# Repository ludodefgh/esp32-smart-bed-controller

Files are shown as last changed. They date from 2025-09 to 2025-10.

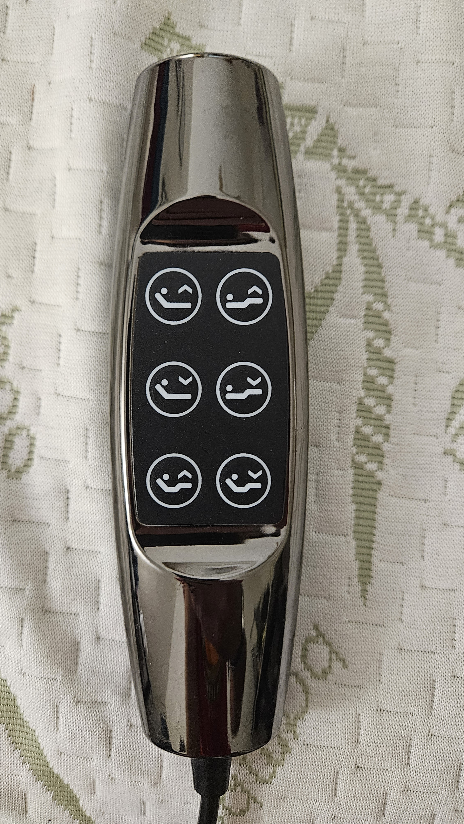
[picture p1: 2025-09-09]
remote.jpg

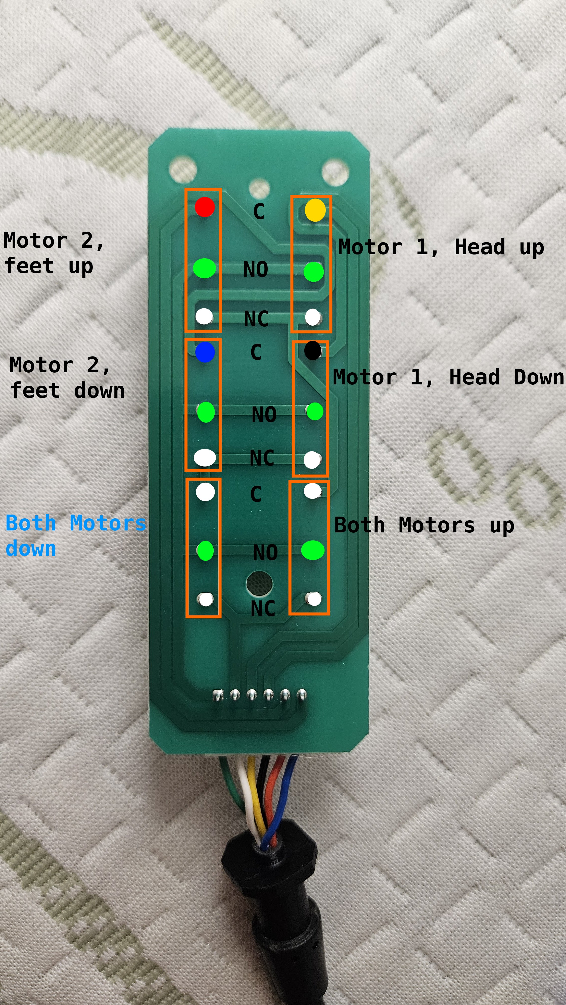
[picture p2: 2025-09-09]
remote-back.jpg

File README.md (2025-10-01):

# Smart Bed Controller with ESP32 and ESPHome

Transform your adjustable bed into a smart home device using an ESP32 microcontroller and ESPHome. This project allows you to control your bed remotely through Home Assistant while preserving the original remote functionality.

## Table of Contents

- [Overview](#overview)
- [Hardware Requirements](#hardware-requirements)
- [Wiring Guide](#wiring-guide)
- [ESPHome Configuration](#esphome-configuration)
- [Home Assistant Integration](#home-assistant-integration)
- [3D Printed Case](#3d-printed-case)
- [Installation Steps](#installation-steps)
- [Troubleshooting](#troubleshooting)
- [Safety Considerations](#safety-considerations)

## Overview

This project enables smart control of adjustable beds by intercepting and replicating the signals from the original remote control. The ESP32 board acts as an intermediary, allowing both the original remote and Home Assistant to control the bed functions.

### Features

- Control bed head and foot positions remotely via Home Assistant
- Preserve original remote functionality
- WiFi connectivity for smart home integration
- Status LED indicator
- Safe relay-based switching

## Hardware Requirements

### Essential Components

| Component | Description | Example Link |
|---|---|---|
| ESP32 Development Board | 4-relay ESP32 board with 7-30V power input | [Amazon Canada](https://www.amazon.ca/dp/B0DF2KVQ3X) |
| USB to TTL Converter | For programming the ESP32 board | [Amazon Canada](https://www.amazon.ca/dp/B07D6LLX19) |
| DIN5 Extension Cable | To interface with bed's control system | [Amazon Canada](https://www.amazon.ca/dp/B0FK5RSHBZ) |

### Tools Needed

- Wire strippers
- Soldering iron and solder
- Multimeter (recommended)
- Screwdriver set

## Wiring Guide

### Understanding the Original Remote

The bed remote uses a DIN5 connector with the following pin configuration:

| DIN5 Pin | Wire Color | Function |
|---|---|---|
| 1 | Red | Motor 2, Terminal 1 (Feet Up) |
| 2 | Yellow | Motor 1, Terminal 1 (Head Up) |
| 3 | Green | Positive (+) Power |
| 4 | Blue/Orange* | Motor 2, Terminal 2 (Feet Down) |
| 5 | Black | Motor 1, Terminal 2 (Head Down) |
| 6 | White | Negative (-) Power |

*Note: Extension cable may use orange instead of blue

### Power Connections

- **Green (+)**: Connect to ESP32 7-30V input and daisy-chain to all relay NO (Normally Open) contacts
- **White (-)**: Connect to ESP32 GND input and daisy-chain to all relay NC (Normally Closed) contacts

### Motor Control Wiring

Split the extension cable, connect the male end to the bed and wire the cables to the board as following :

| ESP32 Relay | Wire Color | Function | DIN5 Pin |
|---|---|---|---|
| Switch 1 COM | Black | Head Down | Pin 5 |
| Switch 2 COM | Orange/Blue | Feet Down | Pin 4 |
| Switch 3 COM | Yellow | Head Up | Pin 2 |
| Switch 4 COM | Red | Feet Up | Pin 1 |

### Remote Preservation Wiring

Connect the remote in the female end of the extension cable and wire the cables to ESP32 GPIO pins to maintain remote functionality:

| ESP32 GPIO | Wire Color | Function |
|---|---|---|
| GPIO 2 | Black | Head Down Detection |
| GPIO 4 | Red | Feet Up Detection |
| GPIO 17 | Yellow | Head Up Detection |
| GPIO 18 | Orange/Blue | Feet Down Detection |
| GND | Green | Ground Reference |

## ESPHome Configuration

The ESP32 runs ESPHome firmware with the provided `SmartBed.yaml` configuration. Key features:

### Relay Configuration

```yaml
output:
  - platform: gpio
    pin: GPIO32
    id: relay_pin_1  # Head Down
  - platform: gpio
    pin: GPIO33
    id: relay_pin_2  # Feet Down
  - platform: gpio
    pin: GPIO25
    id: relay_pin_3  # Head Up
  - platform: gpio
    pin: GPIO26
    id: relay_pin_4  # Feet Up
```

### Switch Definitions

```yaml
switch:
  - platform: output
    id: relay_1
    name: "Head down"
    output: relay_pin_1
  - platform: output
    id: relay_2
    name: "Feet down"
    output: relay_pin_2
  - platform: output
    id: relay_3
    name: "Head up"
    output: relay_pin_3
  - platform: output
    id: relay_4
    name: "Feet up"
    output: relay_pin_4
```

### Remote Button Detection

The configuration includes binary sensors for each remote button that trigger the corresponding relays, ensuring the original remote continues to work alongside the smart controls.

## Home Assistant Integration

Once the ESP32 is running ESPHome, it will automatically appear in Home Assistant as four switch entities:

- `switch.esphome_web_861ea0_head_down`
- `switch.esphome_web_861ea0_head_up`
- `switch.esphome_web_861ea0_feet_down`
- `switch.esphome_web_861ea0_feet_up`

These can be used in automations, scripts, and dashboards.

## 3D Printed Case

A custom 3D printable case is provided to protect the ESP32 board and provide professional mounting options.

### Case Features

- **Snap-fit lid**: Tool-free access for maintenance
- **Cable management**: Two cable entry points with integrated strain relief
- **LED visibility**: Windows for all relay and status LEDs
- **Ventilation**: Slots for heat dissipation
- **Internal wire management**: Channels to secure Dupont connections

### Files Included

- `box.stl` - Main enclosure box for 3D printing
- `cover.stl` - Top cover/lid for 3D printing

### Printing Instructions

**Print Settings:**
- Layer height: 0.2mm
- Infill: 20%
- Support: None required
- Print orientation: Bottom face down for both parts

**Materials:**
- PLA: Recommended for indoor use
- PETG: Better temperature resistance
- ABS: Maximum durability

**Post-Processing:**
1. Remove any stringing or supports
2. Test fit the snap mechanism before assembly
3. Ensure cable holes are clear of debris

### Assembly

1. **Install board**: Mount ESP32 board using M3 screws into integrated posts
2. **Route cables**: Thread cables through strain relief channels and out cable holes
3. **Secure connections**: Use internal channels to manage and secure wire connections
4. **Close case**: Snap lid onto base using integrated tabs

### Mounting Options

**Under-bed mounting (recommended):**
- Position for easy cable routing to bed connection
- Ensure adequate clearance for lid removal

**Wall mounting:**
- Use appropriate anchors for wall type
- Consider cable management to connection points

## Installation Steps

1. **Prepare the Hardware**
   - Cut the DIN5 extension cable in half
   - Strip wire ends and identify each wire's function using a multimeter

2. **Program the ESP32**
   - Install ESPHome
   - Update WiFi credentials in `SmartBed.yaml`
   - Flash the firmware using the USB to TTL converter

3. **Make Connections**
   - Connect power wires (green/white) to ESP32 power input and relay commons
   - Connect motor control wires to relay COM terminals
   - Connect remote detection wires to GPIO pins

4. **Test the System**
   - Verify original remote still functions
   - Test each relay function from Home Assistant
   - Check that movements stop when buttons are released

5. **Install and Secure**
   - Mount the ESP32 board in a safe, accessible location
   - Secure all connections
   - Test final installation

## Troubleshooting

### Common Issues

**Remote not working after installation:**
- Check GPIO connections for remote detection
- Verify pullup resistors are enabled in configuration
- Test continuity of extension cable connections

**ESP32 not responding:**
- Check power connections (7-30V input)
- Verify WiFi credentials in configuration
- Check serial connection for programming

**Bed movements don't stop:**
- Verify NC (Normally Closed) relay connections
- Check that switches return to OFF state
- Review relay configuration in ESPHome

### Safety Checks

- Always test with original remote first
- Verify all movements stop when controls are released
- Check that relays are properly isolated
- Monitor for any unusual heating of components

## Safety Considerations

⚠️ **Important Safety Notes:**

- This project involves modifying electrical systems - ensure you understand basic electrical safety
- Always disconnect power when making connections
- Test thoroughly before regular use
- The original remote should always remain functional as a backup
- Consider having the installation reviewed by a qualified technician

## License

This project is provided as-is for educational and personal use. Modify your bed's electrical system at your own risk.

## Contributing

Feel free to submit issues, improvements, or variations of this design. Photos and documentation updates are especially welcome.

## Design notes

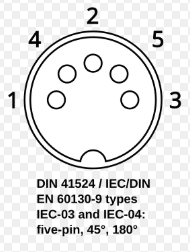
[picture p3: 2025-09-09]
din5-pins.png

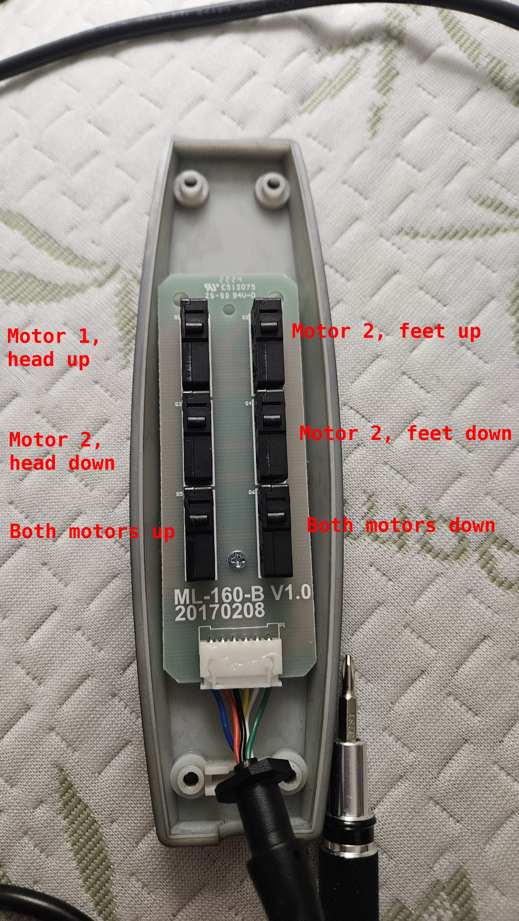
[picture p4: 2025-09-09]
Remote-front.jpg

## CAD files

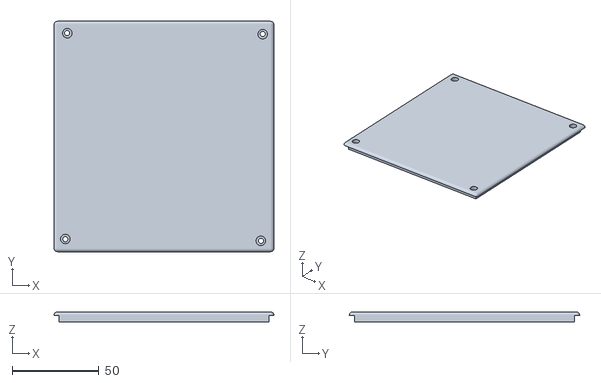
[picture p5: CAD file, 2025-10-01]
cover.stl
127.0 x 133.1 x 6.00

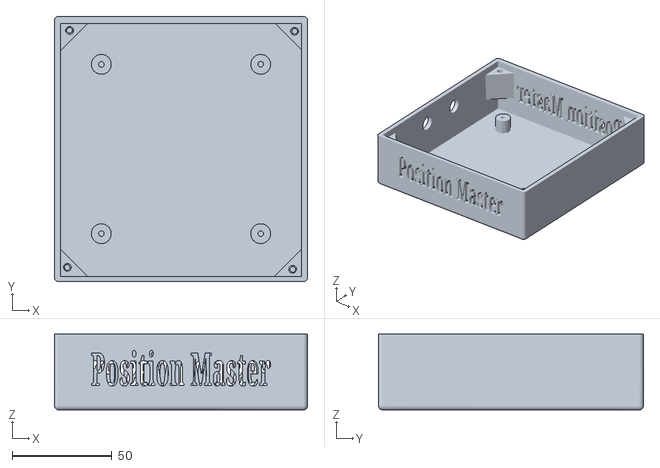
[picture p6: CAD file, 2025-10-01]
box.stl
127.0 x 133.0 x 38.0
